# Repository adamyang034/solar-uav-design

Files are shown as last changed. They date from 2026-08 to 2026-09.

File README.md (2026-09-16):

# Solar UAV Design Toolchain

Models for an 81-hour (89 h with margin) solar-powered flight attempt in the
Mojave desert. Twin-boom, OV-10-style configuration, 6 m span / 12 kg limits.

## Status

- **Phase 1 — environment**: `solar_uav/environment.py`. Clear-sky
  plane-of-array irradiance at the mission site (pvlib/Ineichen), sun-angle
  and reflection (IAM) losses, design-day temperatures, NOCT-style cell
  temperature calibrated to 75 °C at solstice noon.
- **Phase 2 — components**: `solar_uav/components/`
  - `solar_array.py` — SunPower C60 electrical model, boost-MPPT string
    limit, wing/H-stab cell layout with bay/joint constraints.
  - `battery.py` — Upgrade Energy GOLD V1 6S2P bank: SOC window (20–100%),
    6 A/pack charge limit with CV taper, OCV + internal resistance.
  - `propeller.py` — APC PER3 archive plus Mejzlik 2-blade electric
    datasheets/performance maps, thrust/power interpolators with uncertainty.
    - `motor.py` — Hacker A40-12L V4 kv410 direct (default). Geared 10L/10S
      stay in the catalog for comparisons only.
  - `airfoils.py` — NeuralFoil polars (S4110, S4310, AG35, NACA 0010),
    AeroSandbox-native objects for the Phase 3/4 optimization.
- **Phase 3 — aircraft coupling**: `solar_uav/aircraft.py`. Twin-boom
  geometry (H-stab span = boom spacing), mass buildup from measured areal
  densities, NeuralFoil drag polar + induced + parasite, stall/min-power
  speeds, static margin (CG at c/4), elevator trim and pitch acceleration.
  AeroSandbox VLM / AeroBuildup / mesh inertia / XFoil are a conservative
  envelope (`solar_uav/asb_physics.py`): friendlier ASB numbers are discarded.
- **Phase 4 — energy closure + optimizer**: maximize the lower morning SOC,
  requiring next morning SOC not to decrease and retaining the 20% floor.
  `scripts/run_six_layout_study.py` now defaults to an AeroSandbox/IPOPT
  smooth surrogate followed by exact catalog-neighborhood verification.
  It relaxes prop diameter/pitch and pack count alongside geometry, then
  recomputes integer cell packing, battery behavior, and all existing gates.
  The previous differential-evolution search is retained with `--method de`;
  older standalone scripts such as `run_phase34.py` still use that path.
  The 89-hour trace is visualization, not an additional acceptance gate.
  See [surrogate search](docs/surrogate-search.md) and
  [morning SOC and yaw](docs/morning-soc-and-yaw.md).
- **Phase 5 — uncertainty**: `solar_uav/monte_carlo.py`. Sobol sample of
  irradiance, cell temperature, array efficiency, mass growth, drag, APC
  thrust/power factors, avionics, and pack energy. Reports P(closure),
  P10/P50/P90 margin, tornado, and Spearman drivers.
- **Phase 6 — validation**: `solar_uav/validation.py`. Bench/flight
  protocols (panel, battery, thrust stand, glide polar). Drop measured
  CSVs in `data/validation/measured/`; the fitter recommends updates to
  the FLAGGED factors. A synthetic self-test checks the fitter without
  lab data.
- **CAD visualizer**: `solar_uav/cad.py` builds the twin-boom solid
  (AeroSandbox mesh + solar cells + props), writes STL / OpenSCAD, a
  three-view drawing, and `outputs/aircraft_viewer.html`. The four-configuration
  compare view (π-tail, split empennage, conventional, conventional rectangular) is
  `outputs/compare/aircraft_viewer.html` and is what GitHub Pages serves.
  The rectangular option fixes wing taper to 1 and geometric twist to 0;
  the original conventional option still optimizes both. Each has two battery options.
  The engineering workspace includes a read-only overview, baseline comparisons,
  CAD and mass breakdowns, energy histories, requirement headroom, and source
  provenance. See [AircraftView](docs/aircraftview.md) for rebuilding and verification.

```bash
.venv/bin/python scripts/validate_all.py    # Phases 1–2
.venv/bin/python scripts/eval_stability.py  # aileron / fin / loiter
.venv/bin/python scripts/run_asb_audit.py   # AeroSandbox vs handbook
.venv/bin/python scripts/run_phase34.py     # Phases 3–4 + optimizer
.venv/bin/python scripts/run_phase56.py     # Phases 5–6 + CAD
.venv/bin/python scripts/visualize.py       # refresh CAD and open the viewer
.venv/bin/python scripts/run_six_layout_study.py --output outputs/new_surrogate_run
```

## Assumptions

All locked constants and **flagged assumptions** live in
`solar_uav/config.py` — grep for `FLAGGED` to review what still needs test
data or a decision (cell bin, OCV curve, pack DCIR, ESC/gearbox
efficiencies, prop-data uncertainty factors, ambient temps, etc.).

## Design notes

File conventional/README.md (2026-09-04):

# Conventional optimizer (fork)

Clone of the single-empennage toolchain so that folder's results stay
untouched.

**Layout:** one fuselage, one tractor motor/prop, one centerline boom,
conventional tail (H-stab in the wing plane, one V-stab further aft).
No H-stab solar. Packs cap at 3. Props need not be sold in both
rotations.

**Construction:** single 1.5 in boom (FLAGGED: one load path vs two 1 in
twin-boom tubes). Fuselage and ESC fixed masses are not halved.

**Energy (same scoring as the π-tail closer):** GVB-8 buck/boost strings
(cold Voc ≤ 50 V, 210 W panel cap), 2 or 3 packs, two-day march with no
98% refill gate. Boom is 1.5 in (kept).

```bash
.venv/bin/python conventional/scripts/run_phase34.py --search
.venv/bin/python conventional/scripts/visualize.py
```

AircraftView (Phase 4 winner): `http://127.0.0.1:8101/`.
`data/` is a symlink to the parent repository (prop maps, polars).

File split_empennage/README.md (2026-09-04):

# Split-empennage optimizer (fork)

Clone of the π-tail toolchain so that folder's results stay untouched.

**Layout:** two identical fuselages, each with its own T-tail. No bridging
H-stab, no H-stab solar. Tails are **not** sized from `V_H`/`V_V`. The
H-stab is inverted from `SM_MIN = 0.08`. Fins are structural T-tail posts
(boom fitting); weathercock, yaw damping, and differential-thrust yaw
are not constraints. No T-tail downwash credit.

**Construction:** tail surfaces and H-stab/V-stab interfaces are 0.75× the
π-tail areal build (user, FLAGGED until weigh-in). Carbon booms start at
the wing trailing edge, not at c/4.

**Energy (same scoring as the π-tail closer):** GVB-8 buck/boost strings
(cold Voc ≤ 50 V, 210 W panel cap), 2 or 3 packs, two-day march with no
98% refill gate. Wing areal is 0.8× the old 0.84 kg/m² model.

```bash
.venv/bin/python split_empennage/scripts/run_phase34.py
.venv/bin/python split_empennage/scripts/visualize.py
```

Viewer: `split_empennage/outputs/aircraft_viewer.html`.
`data/` is a symlink to the parent repository (prop maps, polars).

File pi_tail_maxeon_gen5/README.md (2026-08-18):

# π-tail optimizer — Maxeon Gen 5 (Kn)

Clone of the single-empennage toolchain with Maxeon Gen 5 cells. Root
`solar_uav/` stays C60.

**Layout:** twin-boom π-tail. One H-stab spans the booms. H-stab chord
floor is one cell row (elevator keep-out), not a full Voc-legal string.

**Cells:** Kn bin (5.84 W, 22.6%), 161.7 mm, 167 mm pitch, 11.6 g.
GVB-8 8 A input is **FLAGGED** and not a search hard-fail (Kn Imp 9.88 A).

```bash
.venv/bin/python pi_tail_maxeon_gen5/scripts/run_phase34.py
.venv/bin/python pi_tail_maxeon_gen5/scripts/run_phase34.py --search
.venv/bin/python pi_tail_maxeon_gen5/scripts/visualize.py
```

Viewer: `http://127.0.0.1:8100/`.
`data/` is a symlink to the parent repository (prop maps, polars).

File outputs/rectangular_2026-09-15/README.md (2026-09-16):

# Conventional Rectangular Wing Study

Separate conventional configuration: constant chord and airfoil across the wing,
taper ratio 1, geometric washout 0 degrees. Whole-wing trim incidence remains
available. Conventional rudder checks, mission assumptions, reserve floor, and
hardware choices are unchanged. The tapered conventional option is preserved.

Both runs use the AeroSandbox/IPOPT surrogate workflow with 72 initial geometry
samples, three refinement rounds, three starts, six workers, and seed 7. Seeds
come from the corresponding conventional result in `../surrogate_final_2026-09-15`;
all seeds are reconstructed as rectangular wings and re-evaluated.

| Battery | Packs | Span (m) | Chord (m) | Mass (kg) | Morning SOC | Reserve above 20% (Wh) |
|---|---:|---:|---:|---:|---:|---:|
| GOLD V1 | 3 | 6.000 | 0.378750 | 10.563 | 29.567% | 138.625 |
| 6S 36 Ah | 2 | 6.000 | 0.390604 | 11.190 | 28.068% | 118.481 |

Both use catalog propeller MJ-20x11EWL and pass the current modeled constraints.
The next-morning SOC condition passes within the existing numerical tolerance.
These are best-found designs, not guaranteed global optima or flight-qualified
aircraft. Structural sizing and existing model uncertainties remain separate.

The two runs performed 663 exact single-prop evaluations in approximately 137
seconds combined. All 486 retained candidate rows have the required fixed geometry.
AircraftView independently recomputed both winners and matched the search SOC
within 0.000001 percentage points. The viewer combines these two cases with the
six preserved cases from `../surrogate_final_2026-09-15`.

Per-case manifests record fixed and active geometry, battery configuration,
source seeds, bounds, and timing. Sample and surrogate diagnostics accompany
each candidate CSV. `browser_qa` contains visual and interaction checks.

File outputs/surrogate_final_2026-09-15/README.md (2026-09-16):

# Final Surrogate-Search Validation

The six-case runner now defaults to a differentiable response-surface search with
AeroSandbox/IPOPT, followed by original-model checks of nearby real catalog props,
allowed integer pack counts, and exact cell packing. See ../../docs/surrogate-search.md.

## Results

All six winners passed fresh energy, hard-constraint, and applicable yaw checks.
The fresh viewer simulations reproduce the final search values to floating-point
precision. These remain preliminary model passes, not flight qualification.

| Layout | Battery | Packs | Mass (kg) | Morning SOC (%) | Reserve above 20% (Wh) |
|---|---|---:|---:|---:|---:|
| Single empennage / pi-tail | GOLD V1 | 3 | 10.843 | 26.1584 | 89.24 |
| Split empennage | GOLD V1 | 3 | 10.135 | 31.4475 | 165.87 |
| Conventional | GOLD V1 | 3 | 9.840 | 37.6531 | 255.79 |
| Single empennage / pi-tail | 6S 36 Ah | 2 | 11.045 | 25.7141 | 83.92 |
| Split empennage | 6S 36 Ah | 2 | 10.363 | 30.7844 | 158.38 |
| Conventional | 6S 36 Ah | 2 | 10.207 | 36.4487 | 241.56 |

The split/36 Ah result improved from 30.5898% to 30.7844% morning SOC (about
2.86 Wh extra reserve). The other five retained their reverified previous winners.

## Runtime

| Case | New run (s) | Prior DE run (s) | Exact single-prop evaluations |
|---|---:|---:|---:|
| Single / GOLD | 76.2 | 436.0 | 259 |
| Split / GOLD | 78.7 | 1157.2 | 273 |
| Conventional / GOLD | 75.4 | 387.2 | 295 |
| Single / 36 Ah | 57.5 | 2235.9 | 239 |
| Split / 36 Ah | 66.8 | 404.9 | 269 |
| Conventional / 36 Ah | 62.1 | 322.4 | 323 |
| Total | 416.9 | 4943.6 | 1658 |

Total recorded case runtime: about 7.0 minutes versus 82.4 minutes previously.
These timings include each case's catalog loading and search, but not viewer
generation, development trials, or browser verification. The new runs warm-start
from the previous optimized geometries. This is not a controlled cold-start
benchmark or a guarantee of the same runtime reduction on future designs.

## Method and Limitations

- 72 additional stratified geometry samples per case, three refinement rounds,
  up to three starts per manufacturer per round, seed 7, six workers.
- Neighbor windows: +/-2.5 inches diameter and +/-2.0 inches pitch, plus nearest
  available SKUs for sparse windows. All catalog variants in the window are tested.
- Twenty selected proposals came from successful IPOPT solves. Sixteen
  manufacturer/round attempts instead used the documented exact-neighborhood
  fallback around known samples. Those fallbacks are not claimed as solver optima.
- The fit is approximate, particularly across cell-packing changes; holdout
  errors, solver failures, trust radii, and predicted/exact scores are recorded in
  each `.surrogate.json`. Fitted scores are never aircraft acceptance results.
- The 16x12E power-map warnings on twin-fuselage designs remain. Structural and
  hardware qualification remain separate; no requirements were loosened.
- Earlier development trials are retained in the other `surrogate_*` directories
  and labeled superseded. This directory contains the final implementation run.

## Verification

The regression suite passes for all three layouts, including analytic-gradient
checks, a known AeroSandbox optimum, catalog-only neighbors, allowed pack counts,
preloaded-map behavior, numerical-bound handling, and morning-SOC/yaw checks.
AircraftView browser checks cover all six selectors, nonblank moving 3D models,
89-hour trace endpoints and chart data, desktop/mobile screenshots, and script errors.

Exact CSVs remain compatible with the existing viewer builder. The published
viewer and fresh verification summary are in ../compare/aircraft_viewer.html and
../compare/study_results.json.

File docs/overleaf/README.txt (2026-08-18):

Solar UAV optimizer guide — Overleaf pack
========================================

Upload this whole folder to Overleaf (New Project → Upload Project),
or zip main.tex + figures/ + this README and drop the zip on Overleaf.

Compiler: pdfLaTeX
Main file: main.tex
Two passes (table of contents + list of figures).

figures/ were generated from the live nearest-miss on 17 August 2026:

  three_view.png        CAD mesh, four views
  geometry_top.png      planform
  geometry_side.png     independent H/V tails
  mass_breakdown.png    kg lumps
  airfoil_polars.png    NeuralFoil @ Re 150k
  drag_budget.png       night drag shares
  power_vs_speed.png    polar + DV(V) and the 1.3 Vs floor
  solstice_day.png      El Mirage irradiance / sun / cell T
  battery_ocv.png       6S OCV vs SOC
  mission_power.png     array vs night/day bus
  mission_soc.png       24 h march
  tradespace.png        812 DE candidates

To refresh the PNGs from the Python model:

  .venv/bin/python scripts/export_overleaf_figures.py

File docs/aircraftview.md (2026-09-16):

# AircraftView Engineering Workspace

AircraftView is a read-only review of eight calculated layout/battery cases.
The engineering interface is authored in `scripts/engineering_view.html` and
`scripts/aircraft_view/`; `scripts/build_compare_viewer.py` regenerates the served
files in `outputs/compare/`. No optimization or physics model was changed for
this redesign.

## Review Views

- Overview: morning SOC, reserve above the floor, mass/headroom, night bus power,
  lift/drag, battery energy, actual CAD mesh, critical requirements and case ranking.
- Compare: select any combination of the eight cases, choose a baseline and view
  absolute values, unit-aware differences or both. Positive does not always mean
  better: only unambiguous performance directions receive green/red coloring.
- Geometry: native generated mesh, camera presets and layers, planform dimensions,
  modeled mass ledger, illustrative inertia and airfoil sections.
- Mass breakdown: total mass, takeoff limit/headroom and battery fraction; whole-
  aircraft allocation pie followed by component pies and expandable constituent
  tables. Select a portion to jump to its detail; units toggle between kg and g.
- Energy: scored morning-cycle quantities separated from the 89-hour display,
  power histories, battery/controller inputs and night drag budget.
- Requirements: model limits, calculated values, dimensional headroom, tolerances,
  and pass/fail/not-evaluated status. These are not structural FoS margins.
- Model & sources: source CSV/manifest, file and current model-source hashes,
  search/recomputed SOC agreement, assumptions, input values and search bounds.

The default interface is monochrome. Color identifies plotted series, CAD
components, statuses and meaningful comparison differences. Light/dark theme is
stored locally. Configuration and view are encoded in the URL, so a link returns
to the same selection. CAD is read-only: legacy browser-only layout and mass edits
are intentionally not consumed as results.

## Data Contract

`engineering_snapshot.py` derives review metadata from the selected `Design`,
active configuration and actual mission acceptance thresholds. Each displayed
case is reconstructed and re-simulated by the existing builder. No stale formatted
overview strings are used as numerical sources. The snapshot retains full-precision
values; presentation rounding does not determine pass/fail.

`mass_allocation.py` derives the mass page from `Design.mass_breakdown()` and the
configured fixed budgets, not from CAD placement lumps. It uses consistent
airframe, battery, solar/power, propulsion and avionics/controls categories across
all layouts. Solar cells and interconnects are separate from airframe structure;
fixed items are assigned once by function. Parent/child sums and the final mass
are checked when building. Detailed spar/rib/fastener masses are not invented.
Identical packs, motors, propellers and controllers use equal per-item allocations.

The snapshot source hash covers the candidate CSV. The model-source hash covers
the current layout package's Python files, not the complete external data/runtime
environment or a historical search-code revision. Run metadata comes from its
saved manifest. The displayed reconstruction check is not empirical validation.

Exports include selected-case JSON (full data/provenance), selected-comparison CSV
(absolute values and provenance), and the actual airframe STL. CSV always exports
unrounded absolute values, regardless of the current delta-display setting.

Model-feasible does not mean flight-qualified. Structural strength, buckling and
aeroelasticity remain explicitly unassessed. Aerodynamic stability's assumed
quarter-chord CG is distinguished from illustrative CAD component positions.
The extended trace starts at full charge and is not the morning-cycle acceptance
test. The old standalone layout viewers are not modified by this redesign.

## Build and Verify

```sh
OPENBLAS_NUM_THREADS=1 VECLIB_MAXIMUM_THREADS=1 OMP_NUM_THREADS=1 .venv/bin/python scripts/build_compare_viewer.py --results-dir outputs/surrogate_final_2026-09-15 --rectangular-results-dir outputs/rectangular_2026-09-15
.venv/bin/python -m unittest discover -s tests -p 'test_*.py'
node tests/check_engineering_view.cjs http://127.0.0.1:8765/aircraft_viewer.html outputs/engineering_review_2026-09-15/qa
node tests/check_mass_view.cjs 'http://127.0.0.1:8765/aircraft_viewer.html?cfg=conventional__6s_36ah&view=mass' outputs/engineering_review_2026-09-15/mass_qa
```

Browser verification requires Playwright, Chrome and Sharp. It checks every case
and view, source agreement, real CAD pixels, camera movement, chart coordinates,
exports, comparisons, filters, dark theme and 390/768/1024/1920-pixel layouts.
Generated UI assets and the icon license live in `outputs/compare/lib/review/`,
which the existing GitHub Pages workflow publishes with the bundled libraries.

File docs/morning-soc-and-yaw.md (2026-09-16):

# Morning SOC and Yaw Acceptance

Updated 2026-09-15.

## Energy Objective

- Start with a full ground-charged battery at the last afternoon solar surplus.
- March through the night without resetting the battery.
- Record current morning SOC immediately before solar surplus begins charging.
- March one complete day to the same charging transition the next morning.
- Require next morning SOC >= current morning SOC. Equality is not required.
- Only 1e-9 SOC of floating-point tolerance is allowed; there is no daily Wh-loss allowance.
- Among feasible aircraft maximize the lower of those two morning SOC values, in percent, not Wh.
- Retain the 20% minimum SOC, unmet-energy, and existing climb checks.

The result fields are `morning_soc`, `next_morning_soc`,
`morning_soc_change`, `morning_charge_hour`, and `objective_soc`.
`soc_start` and `soc_end` now refer to the two morning boundaries.
`margin_wh` still reports energy above the minimum SOC over the scored cycle;
it is not the optimization objective. Failed designs cannot outrank passing
ones just by retaining more energy in a large battery.

Morning is detected from the first daily transition from nonpositive to
positive solar-minus-load power. This uses the existing clear-sky design-day
profile. A profile without a charging transition cannot satisfy this test.
Multiple weather-driven charging episodes would need an explicit event policy
before using a weather-based mission model.

## Visualization and Deferred Work

The main, conventional and separate-tail viewers use an independent 89-hour
SOC/energy trace, beginning at 08:00 with a full battery. The repeated design
day is intentional for visualization; it is not an 89-hour weather forecast
or the acceptance horizon. Bank angle is assumed negligible, so no turning
drag penalty has been added.

The assumed buck/boost MPPT and its current mass are retained. Electrical
capability refinements and structural sizing remain deferred by user decision.

## Yaw and Rudder

Two-motor layouts use differential thrust. Their authority check is independent
of the switch controlling passive yaw-stability requirements. The conventional
single-fuselage layout calls the rudder check directly, without a differential-
thrust capability calculation.

The conventional geometry already included a full-span rudder at 30% of fin
chord and 20 degrees maximum deflection. This installed geometry is retained.
New sizing output reports required versus installed chord fraction, chord,
area, available/required moment, and sideslip/yaw-rate margins.

The existing aerodynamic approximation is retained:

    tau = sqrt(rudder chord / fin chord)
    N_available = q S b Cn_delta_r delta_r_max
    N_required = max(N_sideslip, |N_r| r_required)
    required chord fraction = (N_required / N_per_unit_tau)^2

Sideslip correction and yaw rate are separate cases, as in the original model.
The effectiveness model's 5%-60% chord domain is enforced. A too-small installed
rudder fails; the code does not silently enlarge it or shrink the current rudder.
Servo torque, hinge loads, response time and simultaneous maneuver demands are
not newly validated by this calculation.

For a local smoke check of the saved conventional GOLD V1 winner geometry:

| Quantity | Calculated value |
|---|---:|
| Rudder span | 0.4765 m |
| Installed chord | 0.09531 m |
| Required chord | 0.03277 m |
| Installed area | 0.04542 m2 |
| Required area | 0.01562 m2 |
| Sideslip moment margin | +70.5% |
| Steady yaw-rate moment margin | +736.1% |

This check restored the GOLD V1 pack constants and 20-inch prop diameter; XFoil
was disabled for the local smoke check. It was not a new optimization or a
flight-control certification.

## Verification

Run `.venv/bin/python -m unittest discover -s tests -v` from the repository root.
For each layout, run the same interpreter from that layout directory with
`-m unittest discover -s ../tests -v`. Tests cover rising/equal/falling morning
SOC, precharge boundary timing, absence of charging, feasibility-first ranking,
SOC versus Wh ranking, 89-hour display separation, legacy CSV handling, yaw
routing, and rudder sizing limits.

Existing CSVs and exported HTML are historical artifacts and have not been
overwritten. They do not contain the new morning fields. Rerun the search and
viewer exporter to produce new winning designs and updated exported graphs;
old CSVs retain their historical ranking rather than receiving invented morning
SOC values.

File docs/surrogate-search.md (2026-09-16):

# Differentiable Surrogate Search

## What Was Slow

The previous production search used differential evolution for ten geometry
coordinates, separately for two and three battery packs. Every surviving geometry
ran an inner comparison of the 51 filtered catalog propellers. It was not a full
Cartesian grid of all variables: cell counts came from geometry, cruise speed used
a nested numerical search, and the motor was fixed. Propeller performance maps
were normally cached, but their performance was still evaluated repeatedly.

## New Six-Case Default

1. Load catalog maps once in the parent and distribute them to workers. This also
   avoids concurrent writes to the vendor's local catalog index.
2. Reevaluate up to twelve previous leading designs with the current physics.
   Old mission scores are not imported as training labels or accepted results.
3. Sample every catalog prop at the incumbent geometry and allowed pack counts,
   once, plus 72 stratified geometry samples, half global and half local.
4. Fit smooth, ridge-regularized Gaussian radial-basis models with affine trends
   for morning SOC, minimum SOC, daily SOC change, climb, unmet energy, and the
   original model's feasibility outcome. Analytic leave-one-out error selects
   regularization strength; grouped held-out cases remain separate from tuning.
   Fits use normalized coordinates and are
   separate for APC and Mejzlik. The feasibility fit is a heuristic, not a
   calibrated probability.
5. Use `aerosandbox.Opti` / IPOPT to optimize geometry, continuous pack count,
   diameter, and pitch. Multistart anchors cover both pack counts. Prop proposals
   stay inside the manufacturer's catalog diameter/pitch convex hull and a local
   radius; geometry stays within a bounded local trust region.
   Tolerance-sized solver drift is projected back onto the original bounds
   before exact evaluation; the aircraft limits themselves are unchanged.
6. Check actual SKUs within +/-2.5 inches diameter and +/-2.0 inches pitch of each
   proposed optimum. Keep all catalog variants in that window, filling sparse
   windows with the five closest available SKUs. Check neighboring allowed pack
   counts, including both counts at an endpoint in the current two/three-pack set.
   Also check +/-5 mm chord and boom-spacing changes to cross packing boundaries.
7. Recompute exact geometry, integer cells/strings, real prop maps, prop mass,
   electrical model, yaw, all existing hard gates, and the mission. Add these
   evaluations to training and repeat, three rounds by default. Shrink the trust
   region after poor predictions, no feasible neighbors, or no improvement.

Only exact original-model rows enter the candidate CSV or become winners. A
fractional propeller, fractional battery pack, or fitted SOC result never becomes
a reported aircraft. The previous winner is retained only after current-model
reevaluation. Layouts, battery options, and manufacturer families remain genuine
categories; motor and ESC choices remain fixed as before. Cell counts are smoothed
implicitly in the response versus geometry, not treated as installable fractions.

The current catalog filter is unchanged (including its pitch/diameter window).
If a proposed size is absent, no nonexistent combination is created. For example,
a 22.5 x 23.25 inch prop is outside the current filtered data support.

## Accuracy and Limits

This is surrogate-assisted local optimization, not an end-to-end differentiable
rewrite of the flight model or proof of a global optimum. The numerical solver
can exploit response-surface errors; geometry-dependent packing and hard limits
are particularly difficult to fit. Reports include grouped holdout morning-SOC
RMSE, solver status, predicted versus verified neighborhood SOC, and trust radii.
Large errors reduce the proposal radius; exact verification remains mandatory.

The smooth proposal problem permits up to 0.002 SOC recovery error and 0.1 Wh
unmet energy to avoid rejecting useful neighborhoods purely because of fitting
noise. These are **not** changed aircraft requirements. Final acceptance still
uses the original 1e-9 morning-SOC numerical tolerance, reserve, climb, unmet-energy,
and control checks. Invalid or overly optimistic proposals are discarded.

Runtime comparisons against the archived differential-evolution run are warm-start
workflow comparisons, not equal-budget, cold-start global-search benchmarks.
The one-time catalog sampling/preload cost still exists. Solver failures are
recorded and fall back to exact neighborhoods of known samples, not an unverified
"optimum." Existing structural and hardware/model-uncertainty caveats still apply.

## Commands and Outputs

```sh
.venv/bin/python scripts/run_six_layout_study.py --output outputs/new_surrogate_run --workers 6
.venv/bin/python scripts/run_six_layout_study.py --output outputs/new_de_run --method de --workers 6
```

Optional controls: `--samples`, `--rounds`, `--starts`, `--diameter-radius`,
`--pitch-radius`, `--combo`, and `--seed-dir`. The default seed directory is the
archived six-case morning-SOC run; if a case is missing, its legacy candidate
file supplies geometry seeds instead. A completed run is resumed only with matching search settings and seed path;
use a new output directory after physics/model changes.

Each case writes exact candidates (`.csv`), configuration/timing (`.json`),
surrogate fit/solve diagnostics (`.surrogate.json`), and all sampled inputs plus
their exact outcomes (`.samples.json`). The existing comparison-viewer builder
accepts the new results directory without a different result schema.

Solver API: [AeroSandbox Opti documentation](https://aerosandbox.readthedocs.io/en/master/autoapi/aerosandbox/optimization/opti/index.html).

## Rectangular Conventional Variant

The runner now supports four configurations and two batteries (eight cases);
its historical filename is retained. `conventional_rectangular` reuses the
conventional single-fuselage physics, motor, and rudder checks. It fixes wing
taper ratio to 1 and tip washout to 0. The now-irrelevant taper/washout start
positions are fixed to 1 and 0 respectively. The four fixed coordinates are
removed from the search vector, leaving six geometry variables. Whole-wing
incidence for trim is unchanged; there is no spanwise variation in incidence.

`study_variants.py` applies these restrictions before optimizer import in both
the parent and spawned workers. The viewer validates the reconstructed geometry.
The original conventional configuration remains unrestricted. If no rectangular
seed file exists, conventional geometry seeds are projected into the reduced
search space and re-evaluated; their old mission scores are never reused.

```sh
.venv/bin/python scripts/run_six_layout_study.py --output outputs/rectangular_2026-09-15 --seed-dir outputs/surrogate_final_2026-09-15 --combo conventional_rectangular__gold_v1
.venv/bin/python scripts/run_six_layout_study.py --output outputs/rectangular_2026-09-15 --seed-dir outputs/surrogate_final_2026-09-15 --combo conventional_rectangular__6s_36ah
.venv/bin/python scripts/build_compare_viewer.py --results-dir outputs/surrogate_final_2026-09-15 --rectangular-results-dir outputs/rectangular_2026-09-15
```

The viewer can combine the new cases with the six archived results without
overwriting or rerunning those studies; source CSV paths are retained in its data.

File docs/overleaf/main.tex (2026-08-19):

\documentclass[11pt,letterpaper]{article}

\usepackage[margin=1in]{geometry}
\usepackage{amsmath,amssymb,amsfonts}
\usepackage{booktabs}
\usepackage{longtable}
\usepackage{array}
\usepackage{tabularx}
\usepackage{enumitem}
\usepackage{hyperref}
\usepackage{xcolor}
\usepackage{setspace}
\usepackage{fancyhdr}
\usepackage{caption}
\usepackage{graphicx}
\usepackage{float}
\usepackage{subcaption}
\graphicspath{{figures/}}

\hypersetup{
  colorlinks=true,
  linkcolor=blue!50!black,
  urlcolor=blue!50!black,
  citecolor=blue!50!black
}

\setstretch{1.12}
\setlist[itemize]{leftmargin=1.4em,itemsep=0.25em}
\setlist[enumerate]{leftmargin=1.6em,itemsep=0.25em}
\setlength{\parskip}{0.35em}
\setlength{\parindent}{0pt}

\pagestyle{fancy}
\fancyhf{}
\lhead{Solar UAV optimizer}
\rhead{How the model actually works}
\cfoot{\thepage}

\newcommand{\flag}{\textcolor{red!60!black}{\textbf{FLAGGED}}}
\newcommand{\code}[1]{\texttt{#1}}

\newenvironment{intuition}{\begin{quote}\small}{\end{quote}}
\newenvironment{examplebox}{\begin{quote}\small}{\end{quote}}
\newenvironment{warningbox}{\begin{quote}\small}{\end{quote}}

\title{\textbf{How the Solar UAV Optimizer Works}\\[0.4em]
\large Assumptions, constraints, physics, and what the numbers are trying to tell us}
\author{Design toolchain notes for new members\\
\texttt{solar-uav-design} repository}
\date{17 August 2026}

\begin{document}
\maketitle
\tableofcontents
\listoffigures
\newpage

% =====================================================================
\section{Start here: the one-page mental model}
% =====================================================================

This repository is not a CAD package and it is not a gradient-based ``optimal control'' solver.
It is a \textbf{physics model plus a discrete search}. For each candidate airplane it answers one question:

\begin{quote}
\textit{If this airframe flies a clear-sky solstice day at our site, with our packs and our motors, does the repeating day stay above 20\% overnight and not get poorer?}
\end{quote}

If yes, the design \emph{closes}. If not, the model reports how far it missed, in watt-hours. Nothing on the locked grid currently closes.

The night, not the day, is the problem. On a June solstice the array makes on the order of 200\,W at noon. Cruise only needs about 75\,W of bus power. The airplane still fails because for about \textbf{14 hours} the array cannot cover cruise, and two packs only store 773\,Wh of usable energy.

\begin{intuition}
\textbf{Intuition.} Think of the battery as a water tank, the motors as a tap, and the solar array as a daytime hose. Closing is not ``does the hose fill the tank to 100\%?'' Closing is ``can the tank last until the hose starts working again, and is Tuesday's tank at least as full as Monday's?'' Extra noon solar that you cannot store does not help the night. Launching full is a one-night gift; the scored day is the next one.
\end{intuition}

Three numbers dominate almost every trade:

\begin{enumerate}
  \item \textbf{Night bus power} --- electrical watts the two motors plus avionics draw in level night loiter.
  \item \textbf{Battery-true night length} --- hours when array power is less than that night load (not sunset-to-sunrise).
  \item \textbf{Usable pack energy} --- $2 \times 483\,\mathrm{Wh} \times 80\% = 773\,\mathrm{Wh}$.
\end{enumerate}

Aero, mass, props, and motors all matter only insofar as they move those three numbers.

Source of truth for locked constants: \code{solar\_uav/config.py}. Every value marked \flag{} is an assumption awaiting a measurement or a team decision. The physics rule is: when uncertain, take the \textbf{pessimistic} side. A design must not close because the model was kind.

% =====================================================================
\section{The airplane and the mission}
% =====================================================================

\subsection{What we are designing}

Twin-boom, OV-10-style solar UAV:

\begin{itemize}
  \item One three-piece wing (S4310): rectangular inboard bay between the booms, two outboard panels that may taper. Leading edge unswept.
  \item Independent tails: NACA~0010 H-stab spanning the booms \emph{in the wing plane}; two NACA~0010 V-stabs further aft (fin LE behind H-stab TE). Not a $\pi$-tail.
  \item One tractor propeller and one motor on each boom.
  \item SunPower C60 cells on the wing top and on the H-stab (ahead of the elevator).
  \item Two Upgrade Energy GOLD V1 6S packs in parallel, Genasun GVB-8-Li-25.0V MPPTs (buck and boost; one per string).
\end{itemize}

\begin{figure}[htbp]
  \centering
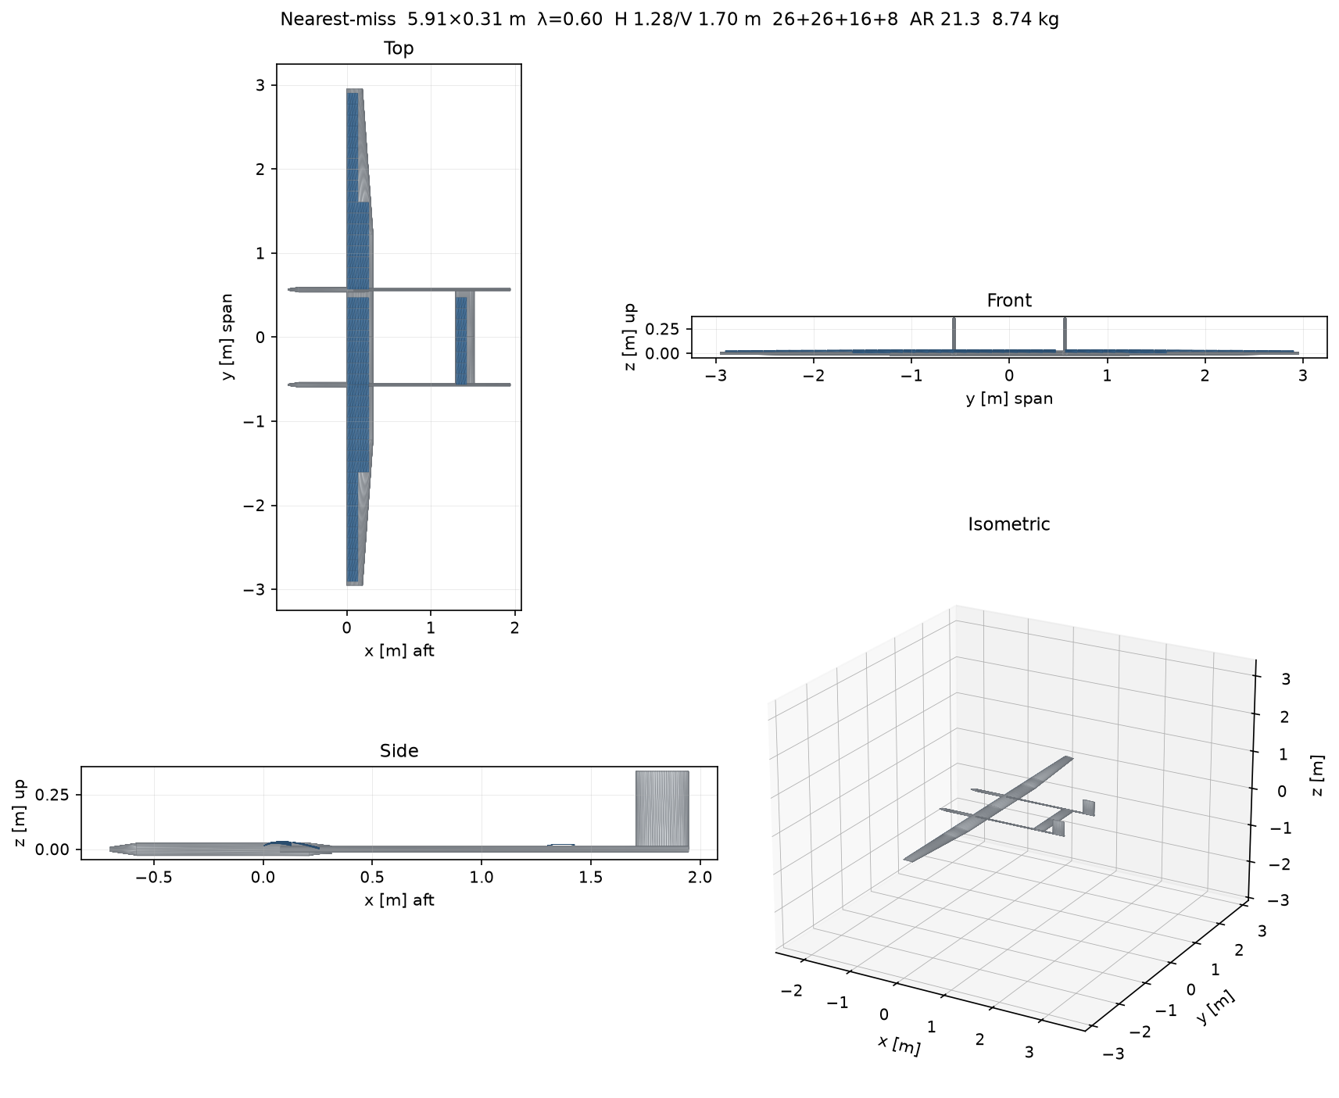
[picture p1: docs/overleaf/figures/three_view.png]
  
  \caption{Current nearest-miss three-view from the live CAD mesh: $5.91\times 0.314\,\mathrm{m}$, $\lambda=0.60$, H-arm $1.28\,\mathrm{m}$, V-arm $1.70\,\mathrm{m}$, 76 cells ($26+26+16+8$), $8.74\,\mathrm{kg}$. H-stab in the wing plane; V-stabs further aft. Blue patches are C60 cells.}
  \label{fig:threeview}
\end{figure}

No payload. The mission is an 81-hour endurance record, designed to 89 hours (10\% margin). The optimizer launches the design day from a full pack (ground charge), then scores the \textbf{next} 24 hours: dawn must stay at or above 20\%, and that repeating day must not get poorer (start $\le$ end). A first night that only survives because you took off full is not closed.

\subsection{Locked mission requirements}

\begin{center}
\begin{tabular}{@{}ll@{}}
\toprule
Quantity & Value \\
\midrule
Site latitude & $34.646849^\circ\mathrm{N}$ (El Mirage Race Course) \\
Site longitude & $-117.605977^\circ$ (El Mirage Race Course) \\
Site elevation & $2837\,\mathrm{ft} = 864.7\,\mathrm{m}$ MSL (USGS lake bed) \\
Cruise AGL & $400\,\mathrm{ft}$ (density at field + AGL; no ground-effect credit) \\
Timezone & America/Los\_Angeles \\
Design day & 21 June 2027 (solstice, longest day) \\
Mission window & 1 May -- 31 July 2027 \\
MTOW & $\le 12\,\mathrm{kg}$ \\
Span & $\le 6\,\mathrm{m}$ \\
Packs & exactly two (no third pack) \\
Avionics & $5\,\mathrm{W}$ continuous, day and night (measured) \\
Climb & $\ge 1.5\,\mathrm{m/s}$ \flag{} \\
Min airspeed & $\max(1.2\,V_\mathrm{stall},\; 15\,\mathrm{kt})$ \\
SOC window & 20\%--100\% (80\% of nameplate is usable) \\
\bottomrule
\end{tabular}
\end{center}

Temperatures are a \textbf{hot design-day}: ambient $24^\circ\mathrm{C}$ dawn to $40^\circ\mathrm{C}$ afternoon \flag{}. A real El Mirage June dawn is often cooler and denser. Keeping $24^\circ\mathrm{C}$ dawn is conservative for night aero. Afternoon $40^\circ\mathrm{C}$ is not a desert extreme --- revisit if cells run hotter than the 75\,$^\circ\mathrm{C}$ noon calibration.

% =====================================================================
\section{The conservative-physics rule}
% =====================================================================

If a number is not measured and not in a datasheet range, the model implements the side that makes closure \emph{harder}.

\begin{itemize}
  \item \textbf{Prop maps.} If the (speed, RPM) point is on the manufacturer table, use that $T$ and $P$, density-scaled. Similarity $C_T(J)$ is a check, or a fallback only while the blade is still below windmill $J$. Never invent a slower RPM at fixed speed once a tabulated block already covers that speed.
  \item \textbf{ESC / motor.} Do not treat 95\% ESC efficiency as valid below $\sim$50\% duty. Low-RPM cruise is not a free no-load-current win.
  \item \textbf{Aero.} Do not take unmodeled credits (T-tail height reducing downwash, flight cooling, swirl recovery) unless they \emph{hurt} the metric you care about. Handbook downwash $2C_L/(\pi\,\mathrm{AR})$ is already coarse --- do not ``improve'' it in the direction that lightens tail download.
  \item \textbf{Mass / solar / battery.} Heavier structure, less array, stricter charge limits --- not the reverse.
\end{itemize}

\begin{warningbox}
\textbf{Why this exists.} An earlier interpolator $n^2$-scaled a $22\times12$E propeller down to $\sim$1190\,RPM at night cruise, inventing $J \approx 1.14$ past the map's zero-thrust $J \approx 0.67$. Night bus looked like $\sim$62\,W and the airplane ``closed.'' The honest operating point on the table is $\sim$2070\,RPM and $\sim$133--138\,W. Prefer an honest fail over an optimistic close.
\end{warningbox}

% =====================================================================
\section{What kind of optimizer this is}
% =====================================================================

File: \code{solar\_uav/optimize.py}.

It is a \textbf{mixed continuous / discrete search}. Aero geometry (span, chord, H-stab arm, V-stab arm, boom spacing, taper, washout, elevator fraction) is continuous and is driven by differential evolution (\code{search\_continuous()}). Integer and catalog quantities stay discrete: cell count from packing, pack count (locked at 2), motor (A40-12L direct), ESC (fixed mass), and the inner-loop propeller pick.

A legacy exhaustive grid (\code{search()}) remains for neighborhood dumps. Do not use it as the production path --- it is the slow nested loop that used to take tens of minutes.

The inner loop (\code{\_best\_prop}) is not part of the outer product. For each airframe it:

\begin{enumerate}
  \item Tries every shortlisted propeller.
  \item Keeps only those that can make night thrust on 6S.
  \item Ranks them by night bus power (lowest first).
  \item Accepts the first that also meets the $1.5\,\mathrm{m/s}$ climb rule.
\end{enumerate}

So ``the optimizer evaluated 51 props'' does \emph{not} mean $51\times$ the airframe grid. Each airplane picks one fan.

Ranking of results: closed designs first, then highest \code{margin\_wh}. If none closed, the top row is the nearest miss.

Default motor is the A40-12L kv410 direct-drive. Geared A40-10L / 10S stay in the catalog for compare scripts only and are not searched.

% =====================================================================
\section{Optimization objective}
% =====================================================================

\textbf{Maximize 24-hour energy margin} (watt-hours above the 20\% SOC floor on the repeating day), subject to periodicity, climb, MTOW, span, solar layout, and trim/pitch.

After the two-day march (day 1 from SOC $=1$, day 2 from wherever day 1 ended),

\begin{align}
  E_\mathrm{reserve}
    &= (\mathrm{SOC}_\mathrm{min} - 0.20)\,E_\mathrm{pack,total}, \\
  E_\mathrm{cycle}
    &= (\mathrm{SOC}_\mathrm{end} - \mathrm{SOC}_\mathrm{start})\,E_\mathrm{pack,total}, \\
  \mathrm{margin}
    &= E_\mathrm{reserve}.
\end{align}

$\mathrm{SOC}_\mathrm{min}$, $\mathrm{SOC}_\mathrm{start}$, and $\mathrm{SOC}_\mathrm{end}$ are all on \textbf{day 2}. $E_\mathrm{cycle}$ is a diagnostic: it must be $\ge -0.5\,\mathrm{Wh}$ to close, but it is not stacked into the score. If the pack could not supply the requested power at any step, margin is also capped at $-\,E_\mathrm{unmet}$.

\begin{intuition}
\textbf{Intuition.} $\mathrm{SOC}_\mathrm{min}$ is ``did we scrape the floor at dawn on the repeating day?'' $\mathrm{SOC}_\mathrm{end} \ge \mathrm{SOC}_\mathrm{start}$ is ``is Tuesday at least as rich as Monday?'' A design that holds 20\% on the first night from a full launch and then ratchets is not a winner. We do not require the pack to hit 98\%.
\end{intuition}

A design is \textbf{closed} only if all of these hold:

\begin{itemize}
  \item $\mathrm{SOC}_\mathrm{min} \ge 0.20$ (day 2)
  \item unmet energy $< 0.5\,\mathrm{Wh}$ (day 2)
  \item climb $\ge 1.5\,\mathrm{m/s}$
  \item $E_\mathrm{cycle} \ge -0.5\,\mathrm{Wh}$ (day 2 does not get poorer)
\end{itemize}

Margin on the current nearest-miss, scored on the repeating day, is worse than the old first-night figure: $\mathrm{SOC}_\mathrm{min} = 0.007$, a $-28\,\mathrm{Wh}$ cycle, and $80\,\mathrm{Wh}$ unmet. The 20\% floor is still what fails. Extra noon solar mostly spills; you need energy \emph{during the night}. The old 98\% refill gate is gone; this row also ratchets.

% =====================================================================
\section{Constraints}
% =====================================================================

\subsection{Hard constraints (candidate is discarded before the mission march)}

Implemented in \code{\_hard\_constraints} and the packing checks:

\begin{center}
\begin{tabular}{@{}lp{0.62\textwidth}@{}}
\toprule
Name & Rule \\
\midrule
Span & $b \le 6\,\mathrm{m}$ \\
Mass & $m \le 12\,\mathrm{kg}$ (re-checked after the prop is chosen) \\
Solar layout & cells fit the bays; each series string stays within the GVB-8 Voc/power cap \\
Stall & $1.2\,V_\mathrm{stall} \le 25\,\mathrm{m/s}$ (sanity cap) \\
Stability & static margin $\ge 8\%\,\mathrm{MAC}$, elevator trim, pitch acceleration $\ge 0.30\,\mathrm{rad/s^2}$, roll rate $\ge 35^\circ/\mathrm{s}$, differential-thrust yaw vs $5^\circ$ sideslip and yaw rate $\ge 5^\circ/\mathrm{s}$ (no rudder). $C_{n_\beta}$ / $|C_{n_r}|$ floors off; derivatives still computed. \\
Boom & carbon tube length $> 0.4\,\mathrm{m}$ \\
V-stab / H-stab & V-stab leading edge at or behind H-stab trailing edge (also enforced by flooring $\ell_v$) \\
Propulsion & some shortlisted prop can make night thrust on 6S \emph{and} climb \\
\bottomrule
\end{tabular}
\end{center}

\subsection{Energy constraints (scored, not discarded)}

Candidates that fail the SOC floor or the day-2 cycle are still written to the CSV so we can see nearest misses. Climb failure also appears in the reason string.

\subsection{Electrical / packing constraints baked into geometry}

\begin{itemize}
  \item One series string per bay on the locked search (inboard, left outboard, right outboard, H-stab). Strings do not cross joints.
  \item The GVB-8 bucks and boosts, so string Voc may sit above the 6S bus. Remaining caps: cold-cell Voc $\le 50\,\mathrm{V}$ (recommended STC Voc; 60\,V is the absolute input) and STC string power $\le 210\,\mathrm{W}$. That is \textbf{61 cells}/string on bin I (the 210\,W rating binds before 50\,V).
  \item Genasun input $\le 8\,\mathrm{A}$; C60 $I_\mathrm{mp} \approx 5.9\,\mathrm{A}$, so one series string per MPPT is fine.
  \item Layout pitch $130\,\mathrm{mm}$ (cell is $125\,\mathrm{mm}$ plus gap). A $300\,\mathrm{mm}$ chord still fits two rows.
  \item After packing, every claimed cell is placed as a $125\,\mathrm{mm}$ square and rejected if it overlaps another cell or hangs off the planform (taper, aileron keep-out, elevator keep-out).
  \item H-stab cells only on the fixed portion; elevator chord is keep-out (split elevons).
  \item Tapered wing: no cells on the aileron chord. Rectangular wing: cells may cover ailerons.
\end{itemize}

% =====================================================================
\section{Decision variables and search grids}
% =====================================================================

Aero variables are continuous. Integer / catalog items stay discrete. Every continuous quantity has a \texttt{(low, high, start)} triple in \code{config.CONTINUOUS}. User-locked starts (chord $310\,\mathrm{mm}$, tail arm $0.90\,\mathrm{m}$, airspeed $12\,\mathrm{m/s}$) are not overwritten.

\begin{center}
\begin{tabular}{@{}lll@{}}
\toprule
Variable & Bounds / start & Notes \\
\midrule
\multicolumn{3}{l}{\emph{In the DE vector}} \\
Span $b$ & $4.50$--$6.00\,\mathrm{m}$, start $6.00$ & hard cap $6\,\mathrm{m}$ \\
Root chord $c_r$ & $0.300$--$0.52\,\mathrm{m}$, start $310\,\mathrm{mm}$ & two C60 rows; high = four pitches \\
H-stab arm $\ell_t$ & $0.80$--$2.00\,\mathrm{m}$, start $0.90$ & wing AC to H-stab AC \\
V-stab arm $\ell_v$ & $0.80$--$3.00\,\mathrm{m}$, start $1.20$ & floored so V-stab LE $\ge$ H-stab TE \\
Elevator fraction & $0.22$--$0.40$, start $0.34$ & split elevons; keep-out for H-stab cells \\
Taper $\lambda = c_\mathrm{tip}/c_r$ & $0.40$--$1.0$, start $0.60$ & $1.0$ is rectangular; $0.40$ still packs a tip cell \\
Taper start & $0$--$1$ of outboard, start $0.50$ & $0$ = taper from the boom \\
Boom spacing & $1.04$--$2.21\,\mathrm{m}$, start $1.30$ & $8$--$17$ cell pitches; H-stab span = boom spacing \\
Washout tip & $0^\circ$--$5^\circ$, start $0^\circ$ & $5^\circ$ is a lot at this AR \\
Washout start & $0$--$1$ of outboard, start $0$ & unused at $0^\circ$ washout \\
\midrule
\multicolumn{3}{l}{\emph{Continuous, nested (not DE)}} \\
Loiter airspeed & $8$--$18\,\mathrm{m/s}$, start $12$, $0.01\,\mathrm{m/s}$ step & still floored by $1.3\,V_s$ / $15\,\mathrm{kt}$ \\
\midrule
\multicolumn{3}{l}{\emph{Continuous, held at start}} \\
H-stab AR & $3.5$--$6.0$, start $4.5$ & not in the DE vector \\
V-stab AR & $1.5$--$3.5$, start $1.5$ & per fin; held at start \\
Aileron chord frac & $0.20$--$0.30$, start $0.25$ & locked for S\&C sizing \\
\midrule
\multicolumn{3}{l}{\emph{Discrete / catalog}} \\
Packs & $\{2\}$ & locked, integer \\
Motor & A40-12L kv410 direct & not searched \\
ESC & fixed $0.060\,\mathrm{kg}$ lump & not searched \\
$N_\mathrm{cells}$ & from packing & integer, one MPPT-legal string per bay \\
Prop & inner loop, see \S\ref{sec:props} & discrete catalog \\
\bottomrule
\end{tabular}
\end{center}

The production search is \code{optimize.search\_continuous()} (differential evolution, start at the DE table above). A neighborhood grid dump is optional via the legacy \code{search()} path.

% =====================================================================
\section{How one candidate is scored}
% =====================================================================

Walk this loop in your head for every row of the CSV.

\begin{enumerate}
  \item Build geometry: planform, boom spacing, H-stab in the wing plane sized to $V_H = 0.50$ (chord also floored by one cell row), V-stabs to $V_V = 0.030$ at their own arm $\ell_v$ (no 1.30\,m area floor), carbon tube from wing $c/4$ to V-stab trailing edge, fuselage pods from wing TE to the prop disk.
  \item Pack cells: one MPPT-legal series string per bay. Reject if cells overlap or hang off the planform.
  \item Sum mass. Drop if $>12\,\mathrm{kg}$.
  \item Check stall, static margin, elevator, pitch, roll rate, weathercock, yaw damping.
  \item For each propeller: night drag at min-power speed $\to$ RPM on the map $\to$ bus watts. Rank by night watts. Keep the cheapest that still climbs at 25.2\,V.
  \item March 24 hours: solar from pvlib, load = night bus or day bus, $P_\mathrm{net} = P_\mathrm{solar} - P_\mathrm{load}$, battery with 6\,A/pack charge cap.
  \item Record $\mathrm{SOC}_\mathrm{min}$, $\mathrm{SOC}_\mathrm{end}$, margin, flags (especially prop table vs.\ similarity).
\end{enumerate}

The rest of this document is the physics inside those steps.

% =====================================================================
\section{Atmosphere and site}
% =====================================================================

Files: \code{solar\_uav/aircraft.py} (density), \code{solar\_uav/environment.py} (sun and temperature).

Site pressure is ISA-style at field elevation plus $400\,\mathrm{ft}$ AGL ($h \approx 987\,\mathrm{m}$ MSL):

\begin{equation}
  p = 101325
  \left(1 - 2.25577\times 10^{-5}\, h\right)^{5.25588}
  \quad [\mathrm{Pa}].
\end{equation}

Density is the ideal-gas law at that pressure:

\begin{equation}
  \rho = \frac{p}{R T}, \qquad R = 287.05\,\mathrm{J/(kg\,K)}.
\end{equation}

Two densities are frozen for the mission (AeroSandbox ISA at field $+$ 400\,ft AGL, with the design-day temperature offset):

\begin{itemize}
  \item Night: $T = 26^\circ\mathrm{C}$ ($T_\mathrm{amb,min}+2$) $\Rightarrow$ $\rho_N = 1.048\,\mathrm{kg/m^3}$.
  \item Day: $T = 36^\circ\mathrm{C}$ ($T_\mathrm{amb,max}-4$) $\Rightarrow$ $\rho_D = 1.014\,\mathrm{kg/m^3}$.
\end{itemize}

Air viscosity is Sutherland's law at the night temperature, $\mu = 1.84\times 10^{-5}\,\mathrm{Pa\,s}$. Reynolds number of a length $\ell$ is

\begin{equation}
  \mathrm{Re}_\ell = \frac{\rho V \ell}{\mu}.
\end{equation}

\begin{intuition}
\textbf{Intuition.} Hot air is thinner, and El Mirage at $\sim$987\,m MSL is already thinner than sea level. A thinner night means the wing needs a higher $C_L$ (or more speed) to hold the same weight, so induced drag rises. Using a hot dawn is deliberately unkind to night watts. Ground effect is not credited: density is at field $+$ 400\,ft AGL, not a cushion of extra lift near the lake bed.
\end{intuition}

% =====================================================================
\section{Geometry}
% =====================================================================

\subsection{Wing planform}

The wing is three pieces. Inboard, between the booms, the chord is $c_r$. Outboard of each boom the chord stays $c_r$ until a taper-start station, then linearly tapers to $c_\mathrm{tip} = \lambda c_r$. Leading edge unswept, so taper is trailing-edge cut.

Let $y_b$ be half the boom spacing and $L_\mathrm{out} = b/2 - y_b$ the outboard panel length. With taper-start fraction $f$ (0 = start at the boom),

\begin{align}
  L_\mathrm{rect} &= f\, L_\mathrm{out}, \\
  L_\mathrm{tap}  &= (1-f)\, L_\mathrm{out}, \\
  S &= 2 y_b c_r + 2 L_\mathrm{rect} c_r + L_\mathrm{tap}(c_r + c_\mathrm{tip}).
\end{align}

Mean aerodynamic chord for an unswept piecewise-linear planform:

\begin{equation}
  \bar{c} = \frac{2}{S}\int_{-b/2}^{b/2} c(y)^2\,\mathrm{d}y.
\end{equation}

Aspect ratio is the usual $ \mathrm{AR} = b^2 / S $.

Boom spacing and area depend on each other (H-stab span = boom spacing, and $V_H$ uses $S$ and $\bar{c}$), so the code iterates that loop 16 times.

\subsection{Horizontal tail}

Target tail volume

\begin{equation}
  V_H = \frac{S_H \ell_t}{S \bar{c}} = 0.50 \quad \text{\flag{}}.
\end{equation}

When boom spacing is forced (e.g.\ $1.30\,\mathrm{m}$), H-stab span equals that spacing and chord is

\begin{equation}
  c_H = \max\left(\frac{V_H S \bar{c}}{\ell_t\, b_\mathrm{boom}},\;
  c_{H,\min}\right),
\end{equation}

where $c_{H,\min}$ is the chord that still fits one $130\,\mathrm{mm}$ cell row after the elevator keep-out. That is why a short tail arm does not shrink the H-stab to nothing: solar packing floors the chord.

\subsection{Vertical tails}

The V-stab aerodynamic centre sits on its own arm $\ell_v$, independent of the H-stab arm $\ell_t$. Total area (both fins)

\begin{equation}
  V_V = \frac{S_V \ell_v}{S b} = 0.030 \quad \text{(user; both fins together)}.
\end{equation}

There is \textbf{no} fin-area floor at a 1.30\,m arm: stretching $\ell_v$ shrinks $S_V$ at fixed $V_V$. Each fin has area $S_V/2$ and $\mathrm{AR}_V = 1.5$ (held at the start of \code{CONTINUOUS}). No rudder; yaw control is differential thrust. No $\pi$-tail endplate credit on $C_{n_\beta}$.

The V-stab leading edge is required to sit at or behind the H-stab trailing edge:

\begin{equation}
  \ell_v \ge \ell_t + 0.75\, c_H + 0.25\, c_V(\ell_v).
\end{equation}

$c_V$ shrinks as $\ell_v$ grows, so the code iterates to the fixed point and floors any requested $\ell_v$ that would overlap the H-stab in $x$.

\subsection{Boom length}

The carbon tube runs from the wing quarter-chord (at the boom) to the V-stab trailing edge. The fuselage pod covers prop disk $\to$ wing trailing edge and is \emph{not} part of $L_\mathrm{boom}$.

\begin{equation}
  L_\mathrm{boom} = x_{\mathrm{V,TE}} - \tfrac14 c_r,
\end{equation}

where $x_{\mathrm{V,TE}} = \tfrac14 \bar{c} + \ell_v + \tfrac34 c_V$. The H-stab camber is in the \textbf{wing plane} ($z_H = 0$); the fins stand up from the boom further aft. Fuselage length and CAD-scaled wetted area (one pod):

\begin{align}
  L_\mathrm{fuse} &= 0.70\,\mathrm{m} + c_r, \\
  S_{\mathrm{wet,fuse}} &= 173128.421\,\mathrm{mm}^2 \times \frac{L_\mathrm{fuse}}{980\,\mathrm{mm}}.
\end{align}

The $980\,\mathrm{mm} / 173128.421\,\mathrm{mm}^2$ point is from CAD. Linear scale assumes constant section (motor/spinner girth does not grow with chord).

\begin{figure}[htbp]
  \centering
  \begin{subfigure}[t]{0.48\textwidth}
    \centering
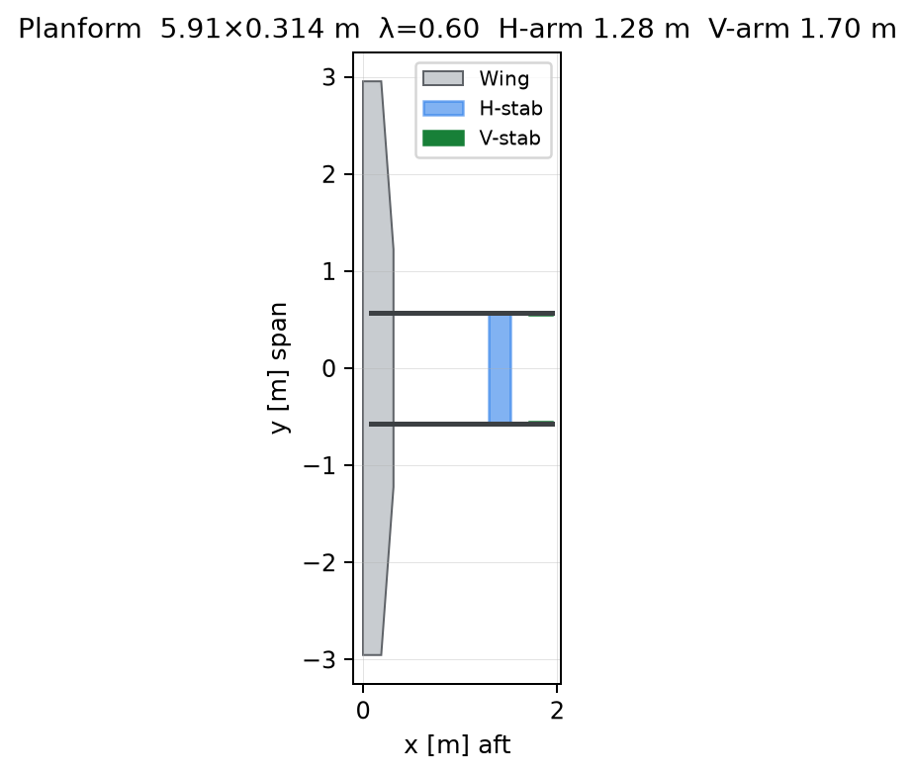
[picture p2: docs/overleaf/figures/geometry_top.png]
    
    \caption{Planform (equal scale).}
  \end{subfigure}\hfill
  \begin{subfigure}[t]{0.48\textwidth}
    \centering
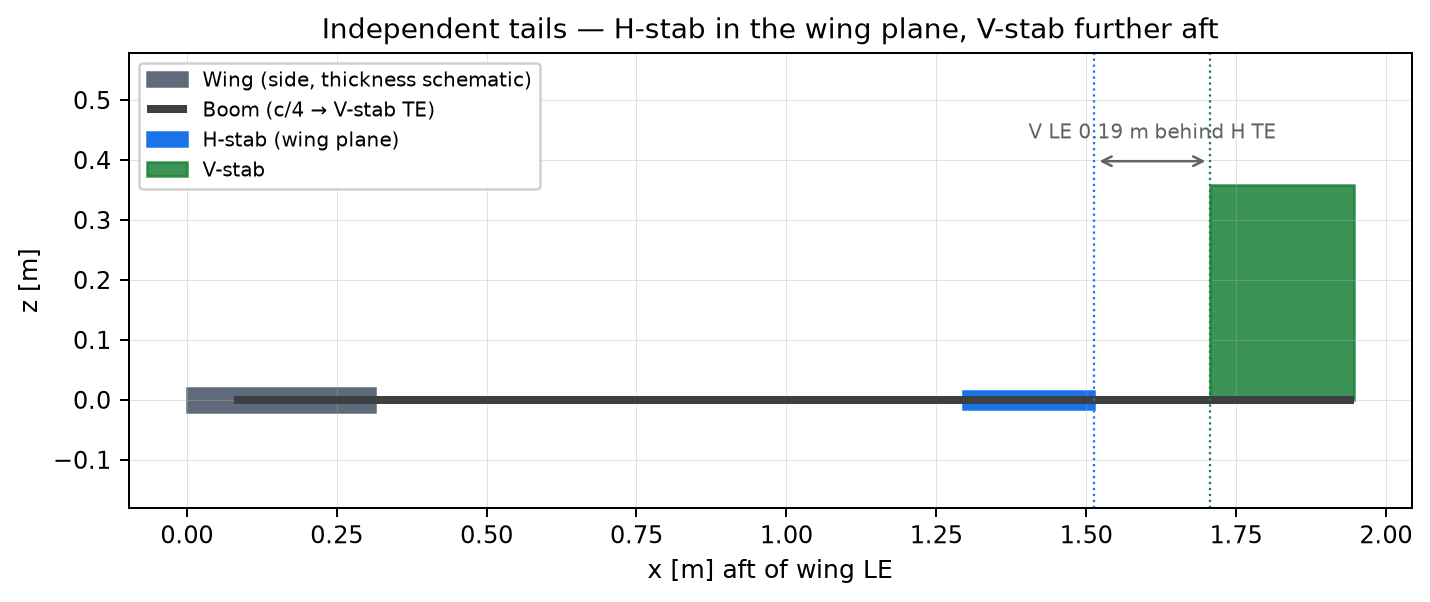
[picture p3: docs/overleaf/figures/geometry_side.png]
    
    \caption{Side schematic.}
  \end{subfigure}
  \caption{Independent tails on the current airplane. Boom runs wing $c/4$ to V-stab trailing edge. V-stab leading edge is $0.19\,\mathrm{m}$ behind the H-stab trailing edge. No $\pi$-tail; $z_H=0$.}
  \label{fig:geometry}
\end{figure}

% =====================================================================
\section{Mass}
% =====================================================================

Wetted-area factor $k_w = 2.05$ (both sides plus a little thickness). Wing structure uses $0.84\times 0.8 = 0.672\,\mathrm{kg/m^2}$ of wetted area (user, 17 August 2026: 0.8$\times$ the previous main-wing model only), \emph{including} encapsulation, \emph{excluding} cells. Tails stay at $0.44\,\mathrm{kg/m^2}$ wetted.

\begin{align}
  m_\mathrm{wing}  &= 2.05\, S \times 0.672, \\
  m_{H}            &= 2.05\, S_H \times 0.44, \\
  m_{V}            &= 2.05\, S_V \times 0.44, \\
  m_\mathrm{booms} &= 2 \times L_\mathrm{boom} \times 0.174\,\mathrm{kg/m}, \\
  m_\mathrm{cells} &= N_\mathrm{cells} (0.0065 + 0.0015)\,\mathrm{kg}, \\
  m_\mathrm{MPPT}  &= N_\mathrm{strings} \times 0.108\,\mathrm{kg}, \\
  m_\mathrm{batt}  &= 2 \times 1.278\,\mathrm{kg}.
\end{align}

Boom linear density $0.174\,\mathrm{kg/m}$ is the 1.0\,in OD carbon tube (was $0.290\,\mathrm{kg/m}$ at $\varnothing 38.1\,\mathrm{mm}$). Parasite drag uses the 25.4\,mm OD.

Fixed masses (prototype table): avionics 0.30, power boards 0.10, servos 0.08, ESCs 0.06, wiring 0.096, fuselage pods 0.20, superstructures 0.20, boom/V-stab interfaces 0.10, boom/H-stab fittings 0.06 (same lump as the old $\pi$-tip joint). Total fixed $= 1.196\,\mathrm{kg}$.

Motors and props are catalog masses (two of each).

\begin{examplebox}
\textbf{Worked example --- current nearest-miss} ($b=5.91$, $c_r=0.314$, $\lambda=0.60$, $\ell_t=1.28$, $\ell_v=1.70$, 76 cells).

\begin{center}
\begin{tabular}{@{}lr@{}}
\toprule
Item & Mass [kg] \\
\midrule
Wing structure & 2.25 \\
H-stab & 0.22 \\
V-stabs & 0.15 \\
Booms ($2\times 1.87\,\mathrm{m}\times 0.174$) & 0.65 \\
Cells + interconnect & 0.61 \\
Four MPPTs & 0.43 \\
Two packs & 2.56 \\
Two A40-12L & 0.55 \\
Two APC $16\times12$E & 0.12 \\
Fixed & 1.20 \\
\midrule
\textbf{Total} & \textbf{8.75} \\
\bottomrule
\end{tabular}
\end{center}

The 0.8$\times$ wing areal cut $\sim$0.6\,kg off the previous 0.84\,kg/m$^2$ wing. The 1\,in tube is both lighter per metre and thinner in parasite drag than the 1.5\,in / 0.290\,kg/m boom. The V-stabs are smaller than a co-located $\pi$-tail at $\ell_t$ because $\ell_v$ is longer at fixed $V_V$. Batteries are still the heaviest single lump.
\end{examplebox}

\begin{figure}[htbp]
  \centering
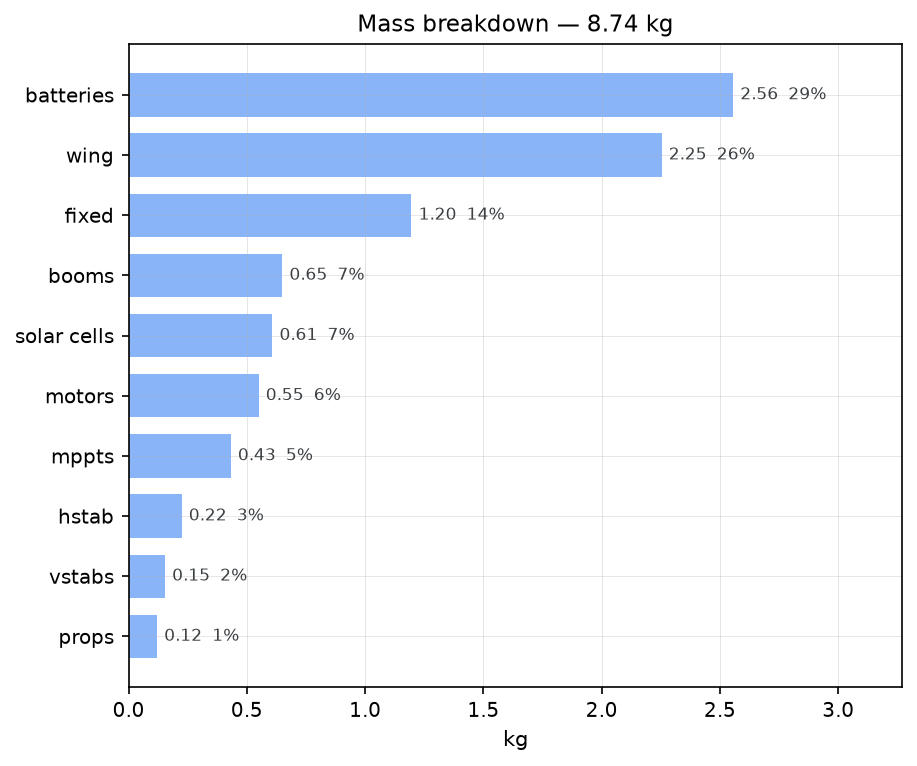
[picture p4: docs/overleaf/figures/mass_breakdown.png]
  
  \caption{Mass lumps on the current nearest-miss. Batteries $2.56\,\mathrm{kg}$ and wing structure $2.25\,\mathrm{kg}$ dominate. Booms are $0.65\,\mathrm{kg}$ at $0.174\,\mathrm{kg/m}$.}
  \label{fig:mass}
\end{figure}

\begin{intuition}
\textbf{Intuition.} You do not ``buy'' span for free. A 6\,m wing at 0.672\,kg/m$^2$ wetted is already $\sim$2.3\,kg before cells. Lengthening $\ell_v$ (not just $\ell_t$) adds carbon on \emph{both} booms, because the tube still runs to the V-stab trailing edge. That extra mass flies all night.
\end{intuition}

% =====================================================================
\section{Aerodynamics}
% =====================================================================

File: \code{solar\_uav/aircraft.py}. Airfoil polars: NeuralFoil \code{xlarge} via AeroSandbox, cached in \code{data/polars/}. Wing section is S4310; tails are NACA~0010. Polar grid: $\mathrm{Re} \in \{50,100,150,200,300\}\times 10^3$, $\alpha \in [-6^\circ, 16^\circ]$ at $0.25^\circ$.

NeuralFoil polars are not monotonic in $C_L$ at negative $\alpha$. The code takes the \textbf{increasing-$C_L$ pre-stall branch} (from $C_{L,\min}$ to $C_{L,\max}$), then interpolates $c_d$, $\alpha$, and $c_m$ versus $C_L$ and $\log\mathrm{Re}$.

\begin{figure}[htbp]
  \centering
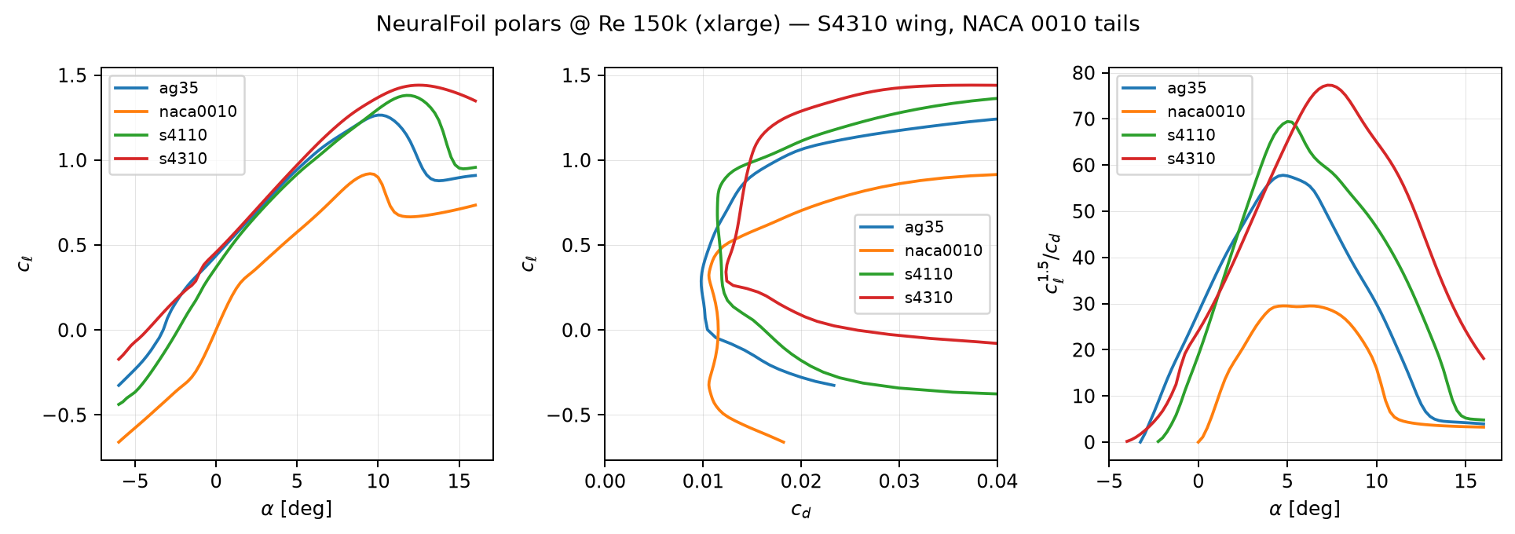
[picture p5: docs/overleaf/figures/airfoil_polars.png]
  
  \caption{Cached NeuralFoil \texttt{xlarge} polars at $\mathrm{Re}=1.5\times 10^5$. Production uses S4310 on the wing and NACA~0010 on both tails.}
  \label{fig:airfoils}
\end{figure}

\subsection{Level-flight lift}

Dynamic pressure and net lift coefficient (weight on the wing reference area):

\begin{equation}
  q = \tfrac12 \rho V^2, \qquad
  C_{L,\mathrm{net}} = \frac{mg}{q S}.
\end{equation}

The H-stab carries a (usually negative) load, so the wing must make a little more than $C_{L,\mathrm{net}}$:

\begin{equation}
  C_{L,w}\, S + C_{L,H}\, S_H = mg
  \quad \Rightarrow \quad
  C_{L,w} = C_{L,\mathrm{net}} - \frac{S_H}{S} C_{L,H}.
\end{equation}

$C_{L,H}$ is not a guess. It comes from the trim iteration below.

\begin{intuition}
\textbf{Intuition.} $C_{L,\mathrm{net}}$ is ``how hard is this wing working, as a whole, to hold the airplane up?'' If the tail is pushing down, the wing has to make \emph{more} lift than the weight, and induced drag is paid on that higher wing $C_L$. That is why a badly trimmed tail is not free.
\end{intuition}

\subsection{Lift-curve slopes (Helmbold)}

Finite-wing lift slope, per radian:

\begin{equation}
  a = \frac{2\pi}{1 + 2/\mathrm{AR}}.
\label{eq:helmbold}
\end{equation}

Used for the wing ($a_w$) and the H-stab ($a_t$ with the H-stab's actual AR). This is the classical correction that a high-AR wing is closer to $2\pi$ and a stubby tail is much less.

Downwash derivative at the tail, handbook:

\begin{equation}
  \frac{\mathrm{d}\varepsilon}{\mathrm{d}\alpha} = \frac{2 a_w}{\pi\,\mathrm{AR}}.
\end{equation}

\subsection{Oswald efficiency (induced-drag factor)}

Rectangular calibration $e_0 = 0.90$ \flag{}. Taper scales that using AeroSandbox's Nita--Scholz estimate:

\begin{equation}
  e = \min\left(0.98,\;
      e_0 \frac{e_\mathrm{Nita}(\lambda_\mathrm{eq},\mathrm{AR})}
               {e_\mathrm{Nita}(1,\mathrm{AR})}\right).
\end{equation}

$\lambda_\mathrm{eq}$ is an equivalent taper from the actual area and tip chord, clipped to $[0.2, 1]$. The 0.98 cap is a hard ceiling: we do not claim a better-than-nearly-elliptical wing.

On the current $\lambda = 0.60$, $\mathrm{AR} = 21.3$ airplane, this \textbf{hits the 0.98 cap}.

\begin{intuition}
\textbf{Intuition.} Induced drag is the price of making lift with a finite wing: the tip vortices tilt the lift vector backward. Elliptical spanload pays the minimum price, $C_{D_i} = C_L^2/(\pi\,\mathrm{AR})$. Oswald $e$ is ``how close are we to that ellipse?'' $e=0.90$ is an honest rectangle. $e=0.98$ is ``this taper already did most of the job.'' That is why adding washout on top of $\lambda=0.4$ does not buy much --- there is almost no induced-drag left to save, and the cap forbids claiming more.
\end{intuition}

\subsection{Induced drag of the wing}

\begin{equation}
  C_{D_i,w} = \frac{C_{L,w}^2}{\pi\,\mathrm{AR}\, e}.
\label{eq:cdi}
\end{equation}

If washout is zero, that is the whole induced model. If washout is nonzero, $e$ is replaced by an effective $e$ from lifting-line (see \S\ref{sec:washout}).

\subsection{Wing profile drag}

At the local $(C_{L,w}, \mathrm{Re}_{\bar{c}})$, read $c_d$ from the S4310 NeuralFoil polar:

\begin{equation}
  C_{D_{p,w}} = c_{d,\mathrm{S4310}}\!\left(C_{L,w},\, \mathrm{Re}_{\bar{c}}\right).
\end{equation}

This is a 2D section drag treated as constant across the span when washout is zero. With washout, a strip integral adds the difference vs.\ the untwisted wing (again \S\ref{sec:washout}).

\subsection{Horizontal-stabilizer drag}

Profile from NACA~0010 at the tail's $C_{L,H}$ and $\mathrm{Re}_{c_H}$. Induced with a conservative tail Oswald $e_H = 0.70$:

\begin{equation}
  C_{D_{p,H}} = c_{d,0010}(C_{L,H}, \mathrm{Re}_{c_H}), \qquad
  C_{D_{i,H}} = \frac{C_{L,H}^2}{\pi\,\mathrm{AR}_H \cdot 0.70}.
\end{equation}

These coefficients are referenced to $S_H$, not $S$.

\subsection{Vertical-stabilizer drag}

Both fins at $C_L = 0$ (no sideslip in the cruise model):

\begin{equation}
  C_{D_{p,V}} = c_{d,0010}(0, \mathrm{Re}_{c_H}),
\end{equation}

referenced to $S_V$ (the H-stab chord Reynolds number is used as a stand-in for the fin). No induced term: they are not lifting in this model.

\subsection{Parasite drag of pods and booms}

Turbulent skin friction (Blasius-like power law, floored at $\mathrm{Re}=10^4$):

\begin{equation}
  C_f = \frac{0.074}{\mathrm{Re}^{0.2}}.
\end{equation}

Two fuselage pods. Wetted area is interpolated from CAD ($173128.421\,\mathrm{mm}^2$ at $L=980\,\mathrm{mm}$), Reynolds number on the actual pod length $L_\mathrm{fuse} = 0.70\,\mathrm{m}+c_r$, form factor 1.25:

\begin{equation}
  f_\mathrm{pods} = 2\, C_f(\mathrm{Re}_{L_\mathrm{fuse}}) \cdot 1.25 \cdot S_{\mathrm{wet,fuse}}(L_\mathrm{fuse}).
\end{equation}

Two circular booms, wetted area $\pi D L$ per tube, $D = 1.0\,\mathrm{in} = 25.4\,\mathrm{mm}$, form/interference 1.10 on the booms, then another 1.10 on the sum:

\begin{align}
  f_\mathrm{booms} &= 2\, C_f(\mathrm{Re}_L) \cdot 1.10 \cdot (\pi D L_\mathrm{boom}), \\
  f_\mathrm{parasite} &= 1.10\,(f_\mathrm{pods} + f_\mathrm{booms}).
\end{align}

$f$ is a drag area: $D = q f$. No laminar-run credit, no T-tail wake shielding.

\subsection{Putting drag together}

\begin{equation}
\begin{aligned}
  D = q \Big[&
      S \bigl(C_{D_{p,w}} + C_{D_{i,w}}\bigr)
    + S_H \bigl(C_{D_{p,H}} + C_{D_{i,H}}\bigr) \\
    &+ S_V C_{D_{p,V}}
    + f_\mathrm{parasite}
  \Bigr] \times k_\mathrm{trim}.
\end{aligned}
\label{eq:drag}
\end{equation}

$k_\mathrm{trim} = 1.00$. There is no lumped ``trim drag fudge.'' Trim is modeled by actually loading the tail.

\subsection{Incidence and trim}
\label{sec:trim}

The wing is jigged so the \textbf{booms fly at $\alpha \approx 0$} at night min-airspeed. That is a structural / packaging choice (the carbon tubes want to be at zero), not an aerodynamic optimum.

NeuralFoil gives the 2D geometric angle $\alpha_{2D}$ that produces the cruise $C_L$ on S4310. The wing also has an induced angle $C_L/(\pi\,\mathrm{AR}\,e)$. Boom angle of attack is

\begin{equation}
  \alpha_\mathrm{boom} = \alpha_{2D} + \frac{C_L}{\pi\,\mathrm{AR}\,e} - i_w.
\end{equation}

Setting $\alpha_\mathrm{boom}=0$ at the design point:

\begin{equation}
  i_w = \alpha_{2D}(C_L) + \frac{C_L}{\pi\,\mathrm{AR}\,e}.
\label{eq:iw}
\end{equation}

On the current airplane, $i_w \approx 3.70^\circ$.

The H-stab is jigged so the \textbf{elevator is $\approx 0$} at that same point. Handbook downwash at the tail:

\begin{equation}
  \varepsilon = \frac{2 C_{L,w}}{\pi\,\mathrm{AR}}
  \qquad \text{(radians; no T-tail height credit)}.
\label{eq:eps}
\end{equation}

Section $c_m$ about $c/4$ from NeuralFoil, tail volume $V_H$, tail lift slope $a_t$:

\begin{equation}
  i_t = \varepsilon + \frac{c_m}{V_H a_t}
  \qquad \text{(angles in consistent units)}.
\label{eq:it}
\end{equation}

On the current airplane, $i_t \approx 0.07^\circ$.

Inside \code{drag\_n}, three iterations:

\begin{enumerate}
  \item From current $C_{L,w}$, get $\alpha_{2D}$ and $\alpha_i = C_{L,w}/(\pi\,\mathrm{AR}\,e)$.
  \item Boom $\alpha_f = \alpha_{2D} + \alpha_i - i_w$.
  \item $C_{L,H} = a_t\,(\alpha_f + i_t - \varepsilon)$.
  \item $C_{L,w} \leftarrow C_{L,\mathrm{net}} - (S_H/S) C_{L,H}$.
\end{enumerate}

\begin{intuition}
\textbf{Intuition for \eqref{eq:eps}.} A lifting wing throws air down. The tail flies in that descending wake, so it sees a more negative angle than the boom. $\varepsilon \approx 2C_L/(\pi\,\mathrm{AR})$ is the standard horseshoe-vortex estimate: more lift or less AR $\Rightarrow$ stronger downwash. A T-tail sits higher, in weaker downwash. The H-stab is in the \textbf{wing plane}, so there is no height credit to take. If VLM at that $z_H=0$ is \emph{stronger} than handbook, production uses VLM (currently $k_\varepsilon \approx 1.21$). We never keep a $k_\varepsilon<1$ ``T-tail'' gift.
\end{intuition}

AeroSandbox is used as a \textbf{conservative envelope}, not as the scoring polar (\code{solar\_uav/asb\_physics.py}):

\begin{itemize}
  \item Atmosphere is the AeroSandbox ISA at field $+$ 400\,ft AGL, with the design-day temperature offset.
  \item Wing-only VLM downwash at the real H-stab height ($z_H=0$): if it is \emph{weaker} than \eqref{eq:eps}, keep the handbook (no T-tail credit). If it is stronger, use VLM. Induced $e$ is $\min(e_\mathrm{handbook}, e_\mathrm{VLM})$.
  \item AeroBuildup $C_{l_p}$, $C_{n_\beta}$, $C_{n_r}$: keep the number that makes roll rate, weathercock, or yaw damping \emph{harder}.
  \item Pitch inertia is $\max($lumped, CAD-located \code{MassProperties} $I_{yy})$. Area-painted thin-shell inertia is printed as a FLAG and not used.
  \item XFoil vs NeuralFoil at cruise $C_L$: inflate section $c_d$ if XFoil is draggier; never deflate. If the XFoil binary is missing, FLAG and keep NeuralFoil.
\end{itemize}

Run \code{scripts/run\_asb\_audit.py} to print the envelope on the reference airplane.

\subsection{Static margin}

CG is locked at the wing quarter-chord \flag{}. Neutral-point shift is then entirely the tail:

\begin{equation}
  \mathrm{SM}
    = V_H \frac{a_t}{a_w}
      \left(1 - \frac{\mathrm{d}\varepsilon}{\mathrm{d}\alpha}\right).
\end{equation}

Target was 12\% MAC; minimum accepted is 8\%. The current airplane sits at \textbf{43\% MAC} --- very stable. $V_H$ comes out $0.69$ rather than the $0.50$ volume target because the H-stab chord is floored by one $130\,\mathrm{mm}$ cell row after the elevator keep-out. That extra tail is packing, not an SM request.

Elevator effectiveness is the empirical stand-in $\tau = \sqrt{c_e/c}$ \flag{}. Elevator must trim a $\Delta C_L = 1$ at $\le 15^\circ$. Pitch acceleration about the CG must reach $0.30\,\mathrm{rad/s^2}$ ($\sim 20^\circ$ in 1.5\,s from rest) at min airspeed.

\subsection{Stall and the speeds we actually fly}

2D $C_{L,\max}$ is the peak of the NeuralFoil pre-stall branch. 3D knockdown:

\begin{equation}
  C_{L,\max,3\mathrm{D}} = 0.90\, C_{L,\max,2\mathrm{D}}.
\end{equation}

For S4310, $C_{L,\max,2\mathrm{D}} \approx 1.44$, so $C_{L,\max,3\mathrm{D}} \approx 1.30$. Stall speed:

\begin{equation}
  V_s = \sqrt{\frac{2mg}{\rho S C_{L,\max,3\mathrm{D}}}}.
\end{equation}

Operational floor (flown loiter speed):

\begin{equation}
  V_{\min} = \max\bigl(1.3\, V_s,\; 7.7\,\mathrm{m/s}\bigr).
\end{equation}

$1.2\,V_s$ remains a never-below stall margin. The 89-hour flight is a banked loiter, so the energy march pays $1.3\,V_s$. The $7.7\,\mathrm{m/s}$ is 15\,kt of required crosswind capability. On the current airplane $1.3 V_s = 11.42\,\mathrm{m/s}$ and \textbf{binds}: unconstrained aero min-power is $\sim$9.2\,m/s ($DV \approx 29\,\mathrm{W}$ vs.\ $36\,\mathrm{W}$ at the floor). That extra 2.2\,m/s is about $+10\,\mathrm{W}$ of night bus.

Cruise is \textbf{not} $V_{\min}$ blindly. It is the speed $\ge V_{\min}$ that minimises shaft power $P_\mathrm{aero} = D V$. The 1-D search is bounded to $8$--$18\,\mathrm{m/s}$, starts at $12\,\mathrm{m/s}$, and refines to $0.01\,\mathrm{m/s}$ (Brent), still floored by the loiter margin. On the current airplane the floor \textbf{is} the min-power point: unconstrained aero min-power is $\sim$9.2\,m/s, but $1.3 V_s = 11.42\,\mathrm{m/s}$ binds.

\begin{intuition}
\textbf{Why min power, not max $L/D$?} Endurance on a battery cares about \emph{watts}, not distance. Max $L/D$ minimises drag (energy per metre). Min $D V$ minimises energy per second. For a solar loiterer the clock is the enemy, so we fly min power. The extra $1.3$ factor (vs.\ $1.2$) is so a $20^\circ$ bank does not eat the stall margin --- $\sqrt{1/\cos 20^\circ}\approx 1.03$, so $1.3$ already covers turn-stall.
\end{intuition}

Climb is the ideal excess-power expression at day min-power speed, using max thrust available on 25.2\,V:

\begin{equation}
  \dot{h} = V \frac{T - D}{mg}.
\end{equation}

No acceleration, no prop-in-climb polar change, no takeoff ground roll. On the 12L + APC $16\times12$E this is $\sim 15\,\mathrm{m/s}$ versus a $1.5\,\mathrm{m/s}$ requirement. Climb is not the constraint. It only vetoes fans that are efficient at cruise but cannot pull.

\subsection{Ailerons, elevons, and fins}
\label{sec:control}

The performance polar does not fly the airplane. Roll, weathercock, and yaw damping are hard constraints so a later sim cannot inherit a 5$^\circ$/s placeholder.

\textbf{Ailerons} are 25\% local chord. On a taper they start where the second cell row drops (or further inboard if 35$^\circ$/s is not met) and carry no cells on the moving surface. On a rectangle, cells may cover the aileron. \textbf{Elevons} are the existing elevator, split left/right, used differentially for extra roll. There is \textbf{no rudder}; yaw is differential thrust.

Steady roll helix (full $20^\circ$ aileron + $20^\circ$ elevon):

\begin{equation}
  \frac{p b}{2V} = -\frac{C_{l_{\delta a}}\delta_a + C_{l_{\delta e}}\delta_e}{C_{l_p}},
  \qquad
  C_{l_{\delta a}} = \frac{2 a_w \tau}{S b}\int_{y_1}^{y_2} c(y)\, y\,\mathrm{d}y.
\end{equation}

$C_{l_p}$ is a high-AR handbook estimate inflated 15\% so the rate is harder to achieve. Acceptance: $p \ge 35^\circ/\mathrm{s}$ at loiter speed ($\sim 20^\circ$ bank in about a second). A 10\,cm tip strip on this wing makes $\sim 5^\circ/\mathrm{s}$ --- that was the sim.

Weathercock and yaw damping (two NACA~0010 fins, Helmbold $a_v$, $\eta=0.90$, no endplate credit):

\begin{equation}
  C_{n_\beta} = \eta a_v V_V, \qquad
  C_{n_r} = -2\eta a_v \frac{S_V}{S}\left(\frac{\ell_v}{b}\right)^2.
\end{equation}

Floors: $C_{n_\beta}\ge 0.10$, $|C_{n_r}|\ge 0.030$ are \textbf{off} (differential thrust is the yaw effector). Derivatives are still computed. Hinge/side-gap drag of ailerons and elevons is added to the polar.

Differential-thrust yaw (one motor $T_{\max}$, the other idle) must overpower weathercock at $5^\circ$ $\beta$. The \textbf{corrective rate} is the still-air heading rate with loiter-preserving $\Delta T$ (one motor up, the other down, sum held at drag) versus $C_{n_r}$:

\begin{equation}
  r = \frac{N_{\mathrm{DT,loiter}}}{q S b\, |C_{n_r}|\, b/(2V)},
  \qquad
  N_{\mathrm{DT,loiter}} = 2\min(T_{\mathrm{cruise}},\, T_{\max}-T_{\mathrm{cruise}})\, y_{\mathrm{boom}}.
\end{equation}

Acceptance: $r \ge 5^\circ/\mathrm{s}$ (unwind $5^\circ$ in about a second). $C_{n_r}$ for this rate is the \emph{more negative} of handbook vs AeroBuildup. $I_{zz}$ sizes the initial $\dot r$ and the 1-DOF time to yaw $5^\circ$; motor spool-up is not modelled, so those two are optimistic. Max-effort (idle one motor) rate is reported and is not the gate.

\textbf{No dihedral} is modelled. Spiral-mode static stability is not claimed; the autopilot is assumed to hold a slow spiral with the sized ailerons.

\subsection{Washout}
\label{sec:washout}

Geometric washout is tip leading-edge down, starting at a station on the outboard panel. \textbf{Zero washout does not change the lumped polar at all} --- the lifting-line code is not even called. That is deliberate, so the published baseline cannot move when someone toggles a unused twist flag.

When twist is nonzero, a Fourier lifting-line (Prandtl / Anderson, 11 odd modes on the half-span, file \code{solar\_uav/lifting\_line.py}) solves

\begin{equation}
  \Gamma(\theta) = 2 b V \sum_{n=1,3,\ldots} A_n \sin(n\theta),
  \qquad y = (b/2)\cos\theta.
\end{equation}

Section lift $c_\ell = 2\Gamma /(V c)$. Wing $C_L = \pi\,\mathrm{AR}\, A_1$. Trefftz-plane Oswald:

\begin{equation}
  e_\mathrm{LL} = \frac{A_1^2}{\sum n A_n^2}.
\end{equation}

The model does \emph{not} replace handbook $e$ with $e_\mathrm{LL}$ outright (that would let an inviscid method invent a better wing than the calibration). It only reports the \emph{ratio} of twisted to untwisted lifting-line $e$, times the handbook value, still capped at 0.98:

\begin{equation}
  e_\mathrm{eff} = \min\left(0.98,\;
    e_\mathrm{handbook} \frac{e_\mathrm{LL,twisted}}{e_\mathrm{LL,untwisted}}\right).
\end{equation}

Strip profile drag is integrated at the collocation stations; only the \emph{increment} vs.\ the same planform untwisted is added. Stall becomes first-strip $C_{L,\max}$, and cannot exceed the untwisted 3D cap.

\begin{examplebox}
\textbf{Example --- why the search refused washout.}
On $\lambda = 0.4$ (and on the current $\lambda \approx 0.60$) the spanload is already near-elliptical, $e$ is already at the 0.98 cap. Twist cannot raise $e$ further. It \emph{can} unload the tip (good for stall) but the first-strip rule and the profile-drag increment make cruise slightly worse. The current search parked washout at $\approx 0^\circ$. On a \emph{rectangular} wing, washout does raise $e$ ($0.90 \to \sim 0.95$), but flying a rectangle to get that twist benefit also adds tip chord, cells, mass, and drops AR. That package still lost on margin. The optimizer's message: \textbf{taper already bought the induced-drag win; do not pay mass for a second copy of the same win.}
\end{examplebox}

\subsection{Worked drag budget (current night cruise)}
\label{sec:dragbudget}

$m = 8.745\,\mathrm{kg}$, $V = 11.42\,\mathrm{m/s}$ ($1.3 V_s$ binds), $\rho = 1.048$, $q = 68.3\,\mathrm{Pa}$, $S = 1.636\,\mathrm{m^2}$.

\begin{center}
\begin{tabular}{@{}lrrr@{}}
\toprule
 & $C_L$ / $C_D$ & Drag [N] & Share \\
\midrule
Net airplane $C_L$ & 0.768 & & \\
Wing $C_L$ & 0.784 & & \\
H-stab $C_L$ & $-0.109$ & & \\
Wing profile (S4310, $\mathrm{Re}_{\bar{c}}\approx 1.84\times 10^5$) & $C_{D_p}=0.0123$ & 1.38 & 44\% \\
Wing induced ($e=0.98$) & $C_{D_i}=0.0094$ & 1.05 & 33\% \\
H-stab profile & & 0.20 & 6\% \\
H-stab induced ($e_H=0.70$) & & 0.018 & 1\% \\
V-stab profile ($C_L=0$) & & 0.14 & 4\% \\
Pods & & 0.17 & 5\% \\
Booms ($\varnothing 25\,\mathrm{mm}$, $L=1.87\,\mathrm{m}$) & & 0.11 & 4\% \\
Control-surface gaps & & 0.10 & 3\% \\
\midrule
\textbf{Total} & $C_D=0.0283$ on $S$ & \textbf{3.16} & \\
Aero power $DV$ & & \textbf{36.1 W} & \\
$L/D$ & 27.1 & & \\
\bottomrule
\end{tabular}
\end{center}

\begin{intuition}
\textbf{Read this table like a designer, not an aerodynamicist showing off.} About 77\% of cruise drag is the wing. Profile now beats induced (44\% vs.\ 33\%) because the airplane is lighter and is forced to fly $1.3 V_s$ instead of aero min-power. Unconstrained min-power is $\sim$9.2\,m/s and $DV \approx 29\,\mathrm{W}$; the speed floor costs about $7\,\mathrm{W}$ of aero and $\sim$10\,W of bus. The entire empennage plus pods plus booms plus gaps is $\sim$0.74\,N. Polishing boom fairings will not close a 158\,Wh night gap. The remaining polar levers at fixed mass are $C_{L,\max}$ (or relaxing $1.3\to 1.2$) and wing profile $C_D$. Span and $e$ are already maxed.
\end{intuition}

Aero power 36\,W is \emph{not} night bus power. The propeller, motor, ESC, and the 5\,W avionics sit between $DV$ and the battery. That chain currently turns 36\,W of aero into $70.2\,\mathrm{W}$ of propulsion plus $5\,\mathrm{W}$ avionics $= 75.2\,\mathrm{W}$ on the bus. Propulsion, not the polar, is where most of the remaining watts live.

\begin{figure}[htbp]
  \centering
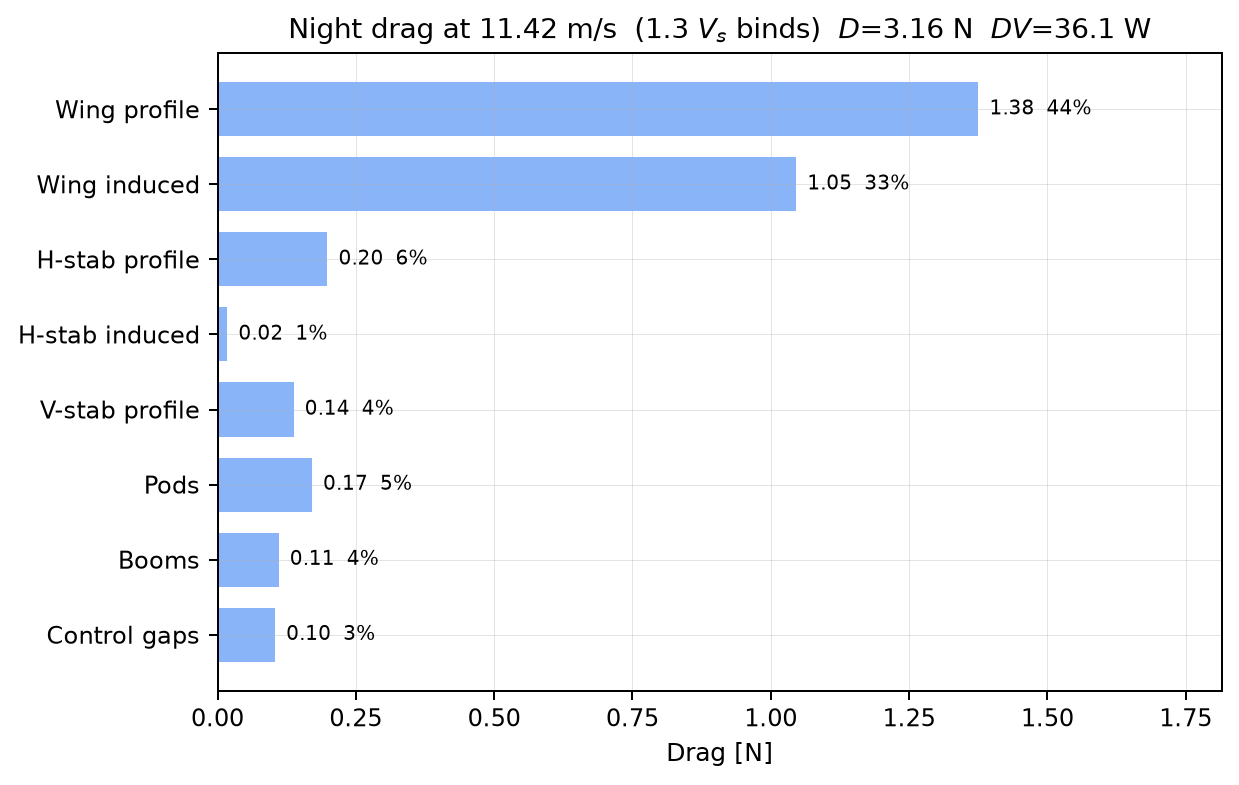
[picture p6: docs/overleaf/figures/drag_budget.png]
  
  \caption{Night drag budget at the flown speed $1.3 V_s = 11.42\,\mathrm{m/s}$. Wing profile 44\%, induced 33\%. Empennage plus pods, booms, and gaps is the remaining quarter.}
  \label{fig:drag}
\end{figure}

\begin{figure}[htbp]
  \centering
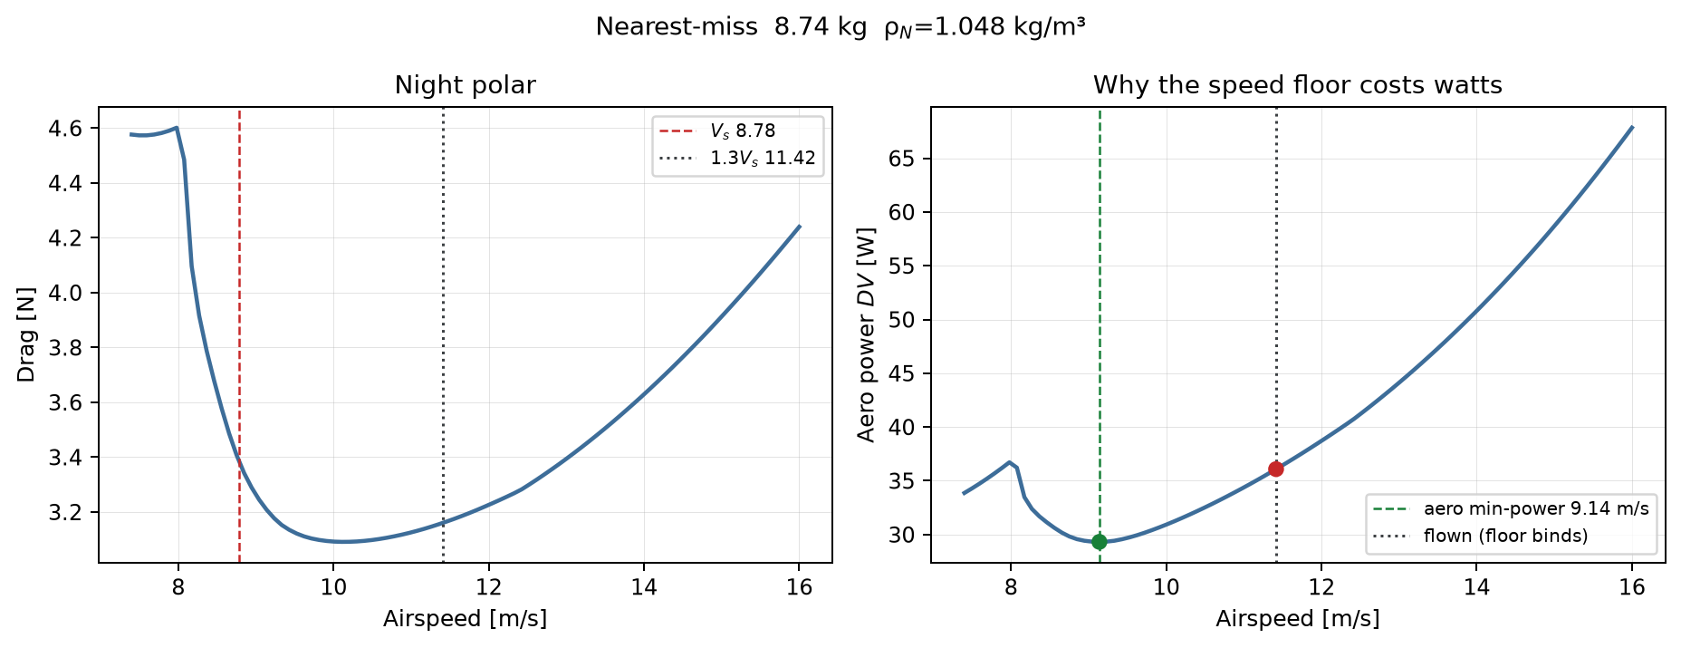
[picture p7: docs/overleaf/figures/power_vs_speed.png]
  
  \caption{Night polar and $DV(V)$. Unconstrained aero min-power is $\sim$9.2\,m/s ($DV\approx 29\,\mathrm{W}$). The $1.3 V_s$ floor binds at $11.42\,\mathrm{m/s}$ and costs about $7\,\mathrm{W}$ of aero / $\sim$10\,W of bus.}
  \label{fig:power-speed}
\end{figure}

% =====================================================================
\section{Solar array}
% =====================================================================

Files: \code{solar\_uav/environment.py}, \code{solar\_uav/components/solar\_array.py}.

\subsection{Sun}

pvlib Ineichen clear-sky at the site, minute resolution. The array is \textbf{horizontal} (wing top). Angle of incidence equals the solar zenith angle.

Plane-of-array irradiance before cells:

\begin{equation}
  E_\mathrm{POA}
    = \underbrace{E_\mathrm{DNI}\cos\zeta \cdot \mathrm{IAM}(\zeta)}_{\text{beam, with reflection}}
    + \underbrace{0.95\, E_\mathrm{DHI}}_{\text{diffuse IAM \flag{}}}.
\end{equation}

Then encapsulation transmission 0.97 \flag{}:

\begin{equation}
  E_\mathrm{eff} = 0.97\, E_\mathrm{POA}.
\end{equation}

IAM is pvlib's physical air/glass model. A horizontal wing at El Mirage ($34.65^\circ\mathrm{N}$) never sees the sun overhead except near noon in June, and even then $\zeta \ne 0$ most of the day. That cosine is the main reason ``battery night'' is longer than civil night.

\subsection{Cell temperature}

No flight-cooling credit. NOCT-style

\begin{equation}
  T_\mathrm{cell} = T_\mathrm{amb} + k\, E_\mathrm{eff},
\end{equation}

with $k$ calibrated so solstice-noon static $T_\mathrm{cell} = 75^\circ\mathrm{C}$ (user requirement). Ambient is a sinusoid, min at 05:00, max at 15:30, between 24 and $40^\circ\mathrm{C}$.

\subsection{Electrical output}

C60 bin I \flag{}: $P_\mathrm{mp} = 3.40\,\mathrm{W}$ at STC. Temperature coefficient $\gamma = -0.32\%/^\circ\mathrm{C}$. Wiring / mismatch / soiling 0.965 \flag{}. MPPT 0.95.

\begin{equation}
  P_\mathrm{bus}
    = N_\mathrm{cells}\, P_\mathrm{mp}
      \frac{E_\mathrm{eff}}{1000}
      \bigl[1 + \gamma (T_\mathrm{cell}-25)\bigr]
      \times 0.965 \times 0.95.
\end{equation}

\subsection{String voltage and power (GVB-8)}

The GVB-8 input range is $0$--$60\,\mathrm{V}$ and it charges a 25\,V bus from a panel that may sit above or below that bus (buck and boost). The old rule ``string Voc must stay below the depleted 6S bus so the converter can always boost'' is therefore dropped. Remaining datasheet caps, evaluated conservatively:

\begin{equation}
  N_{\max} = \min\left(
    \left\lfloor \frac{50}{V_\mathrm{oc}(10^\circ\mathrm{C})} \right\rfloor,
    \left\lfloor \frac{210\,\mathrm{W}}{P_\mathrm{mp,STC}} \right\rfloor
  \right)
  = \min(70, 61) = 61
\end{equation}

on bin I ($V_\mathrm{oc}(10^\circ\mathrm{C})\approx 0.713\,\mathrm{V}$, $P_\mathrm{mp}=3.40\,\mathrm{W}$). The 210\,W recommended panel power binds first. A bay that wants more than 61 cells still needs a second string (extra MPPT mass) or it is illegal under one-string-per-bay.

\begin{examplebox}
\textbf{Example --- extra cells lost.} A mixed-pack rectangular wing with 92--104 cells and extra strings was tried (``just put more solar on''). AR fell to $\sim$16.7, mass rose $\sim$1.4\,kg, night watts rose, and margin got \emph{worse} (about $-184\,\mathrm{Wh}$ vs.\ $-160\,\mathrm{Wh}$ on the tapered 82-cell wing, at the old 410\,g/m booms). Noon already spills. The night does not care that you had 20 more cells at 13:00. It cares that you are heavier and draggier at 02:00.
\end{examplebox}

\begin{figure}[htbp]
  \centering
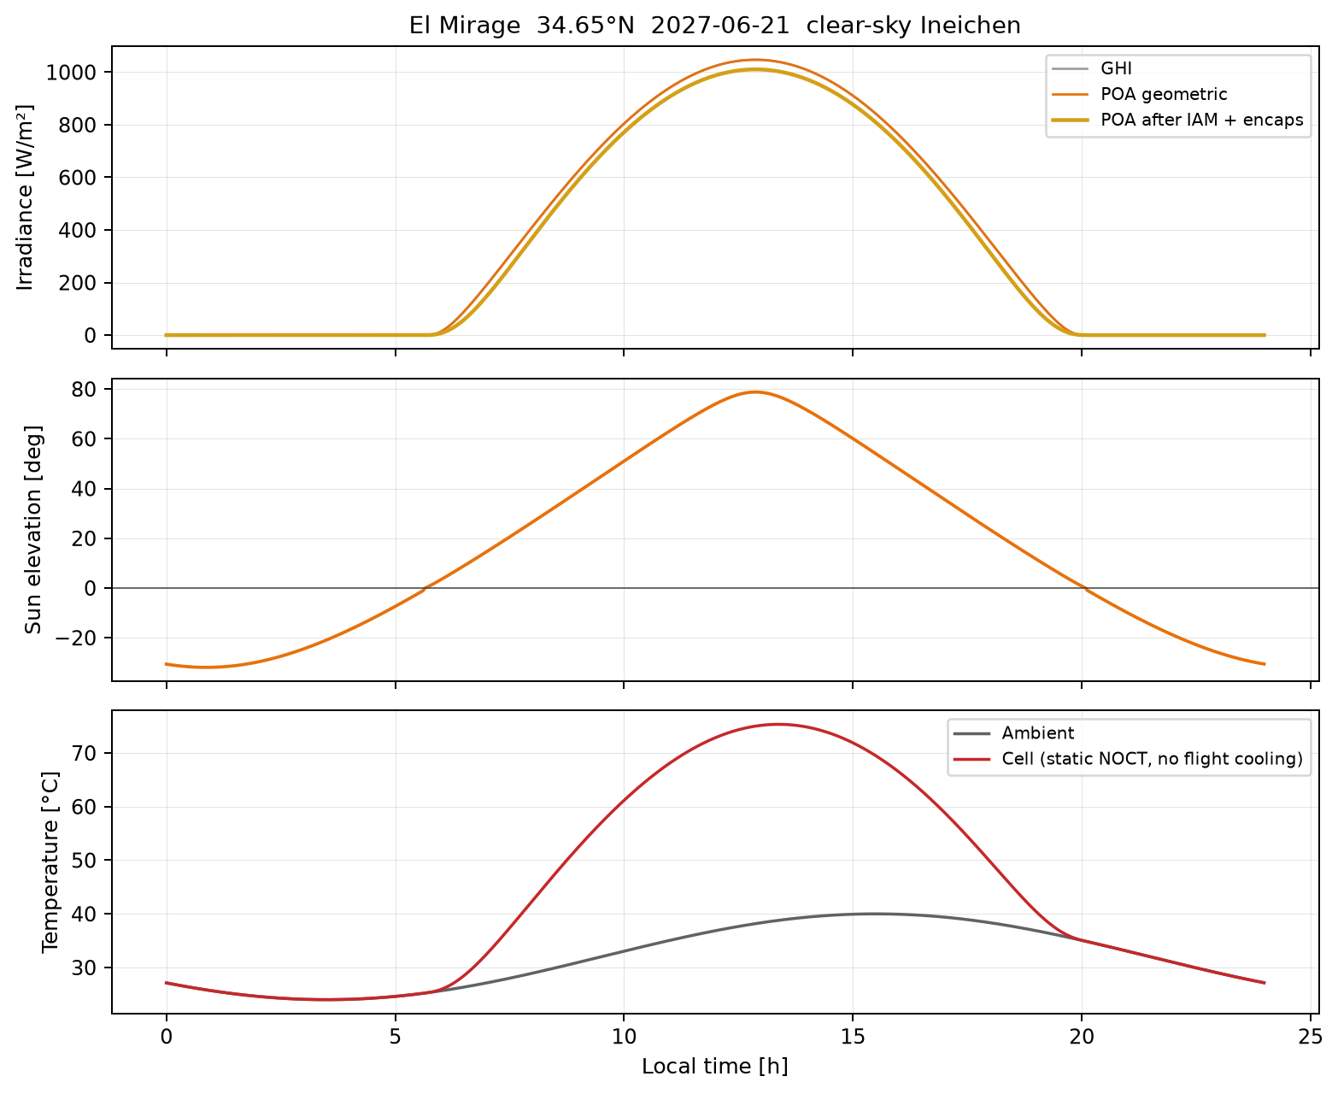
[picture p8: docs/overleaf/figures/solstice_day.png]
  
  \caption{El Mirage solstice design day: Ineichen GHI and plane-of-array after IAM and encapsulation, sun elevation, and the hot static cell-temperature model (no flight-cooling credit). Peak cell $T$ is calibrated to $75^\circ\mathrm{C}$.}
  \label{fig:solstice}
\end{figure}

% =====================================================================
\section{Battery}
% =====================================================================

File: \code{solar\_uav/components/battery.py}.

Two GOLD V1 packs in parallel: 483\,Wh, 23.68\,Ah, 1.278\,kg, 6\,A charge, 313\,W sustained discharge each. Usable energy at the 20\% floor:

\begin{equation}
  E_\mathrm{usable} = 2 \times 483 \times 0.80 = 773\,\mathrm{Wh}.
\end{equation}

SOC is energy-based. Open-circuit voltage is a generic Si-anode Li-ion curve \flag{}, 3.0--4.2\,V/cell, times 6. Internal resistance $45\,\mathrm{m}\Omega$ per pack \flag{}, paralleled.

Terminal power during discharge: $P = V_\mathrm{oc} I - I^2 R$. Chemistry energy removed is $V_\mathrm{oc} I \Delta t$ (you pay $I^2R$ from the bus but it does not come out of SOC as extra capacity --- it is a conversion loss). Charge is the reverse, capped at 6\,A/pack, with a CV taper as $V_\mathrm{oc}$ approaches 25.2\,V.

The march \emph{allows} SOC to fall through 20\% so we can measure how far a miss is. Closure still requires staying above 20\%.

\begin{figure}[htbp]
  \centering
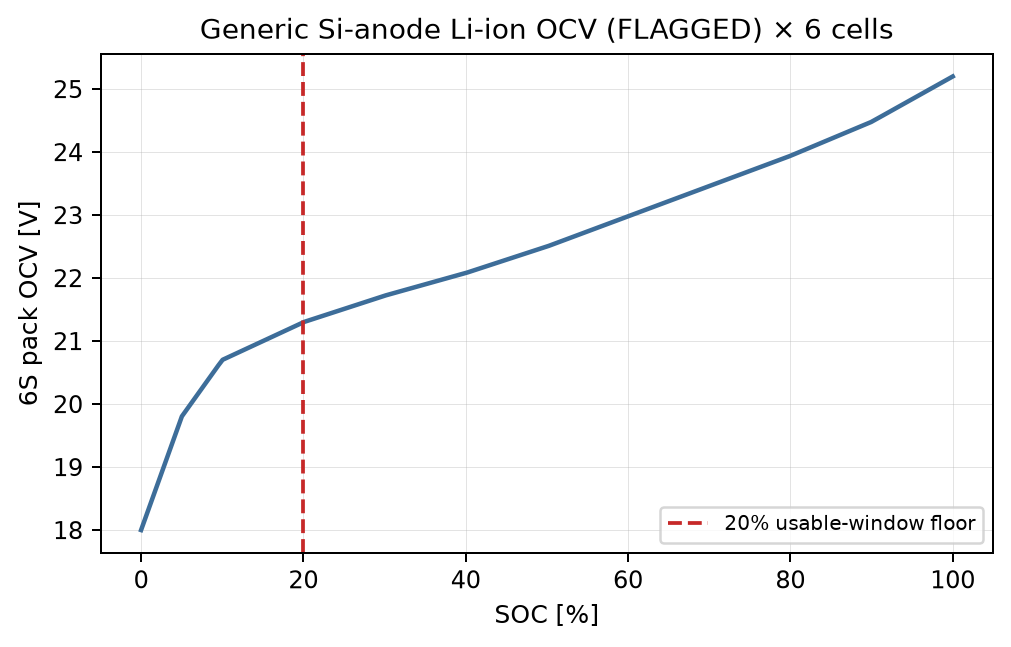
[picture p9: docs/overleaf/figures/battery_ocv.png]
  
  \caption{FLAGGED generic Si-anode OCV curve, times 6. The 20\% floor is the same 80\% usable window as the 773\,Wh pack budget.}
  \label{fig:ocv}
\end{figure}

% =====================================================================
\section{The 24-hour energy march}
% =====================================================================

File: \code{solar\_uav/mission.py}. Default step: 5 minutes.

Night and day bus loads are each a single number: propulsion at that density's min-power speed, plus 5\,W avionics. Then, at every timestep,

\begin{align}
  \text{is\_night} &= (P_\mathrm{solar} < P_\mathrm{night}), \\
  P_\mathrm{load} &= \begin{cases}
      P_\mathrm{night} & \text{if night}, \\
      P_\mathrm{day} & \text{if day},
    \end{cases} \\
  P_\mathrm{net} &= P_\mathrm{solar} - P_\mathrm{load}.
\end{align}

\begin{warningbox}
\textbf{Do not mentally replace $P_\mathrm{net}$ with $-P_\mathrm{night}$ at dusk.} If the array is making 60\,W and the load is 75\,W, the pack only supplies 15\,W. Calling that ``night'' and draining 75\,W is how people convince themselves the physics is worse than it is --- and then over-correct with a third pack. The code already counts the shoulders.
\end{warningbox}

The march starts at the \textbf{last afternoon timestep} where $P_\mathrm{net} > 1\,\mathrm{W}$, with SOC $= 1$ (launch / ground charge), wraps 24 hours, then repeats that wrap \textbf{without resetting the pack}. Day 2 is the scored loop: the night is fully counted, and we test that Tuesday is not poorer than Monday.

\textbf{Battery-true night} is hours with $P_\mathrm{solar} < P_\mathrm{night}$. On 21 June at El Mirage ($34.65^\circ\mathrm{N}$) that is \textbf{14.0 hours} on the current airplane, not the $\sim$9.5 hours of civil night. A horizontal wing at this latitude simply does not make cruise power at low sun.

\begin{examplebox}
\textbf{Example --- why ``75\,W $\times$ 14\,h = 1050\,Wh, we need another pack'' is the wrong arithmetic.}
Usable pack is 773\,Wh. Shoulders (dawn/dusk when the array makes some but not all of cruise) contribute on the order of 100+\,Wh that a naive $P\times t$ ignores. The honest integral is still larger than 773\,Wh --- that is why we miss. On the repeating day the nearest-miss bottoms at $\mathrm{SOC}=0.007$ with a $-28\,\mathrm{Wh}$ cycle. Closing is ``about 11\,W off the night bus'' or ``a bit more pack,'' not ``the polar must be twice as good.''
\end{examplebox}

\begin{figure}[htbp]
  \centering
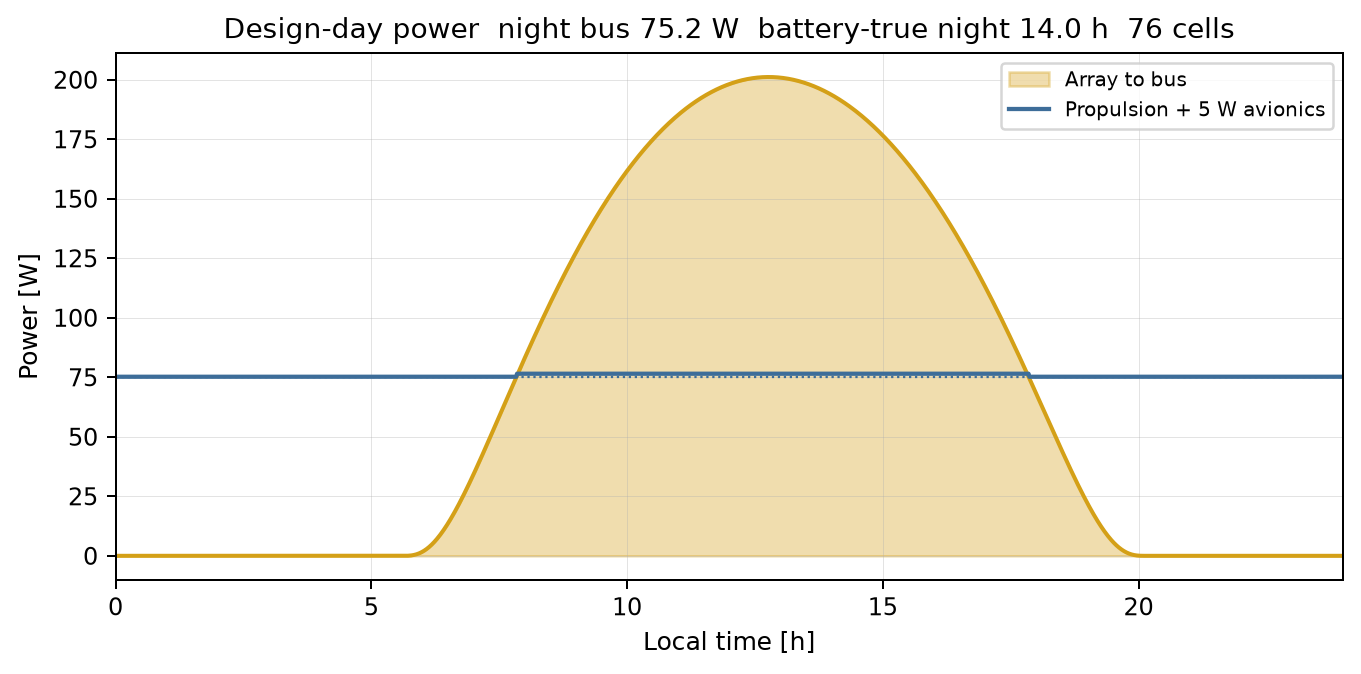
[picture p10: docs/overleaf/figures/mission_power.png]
  
  \caption{Local-time power on 21 June. Array peaks near $200\,\mathrm{W}$; cruise is $75\,\mathrm{W}$. Battery-true night is the 14.0\,h where the gold curve is below the blue load, not civil sunset-to-sunrise.}
  \label{fig:mission-power}
\end{figure}

\begin{figure}[htbp]
  \centering
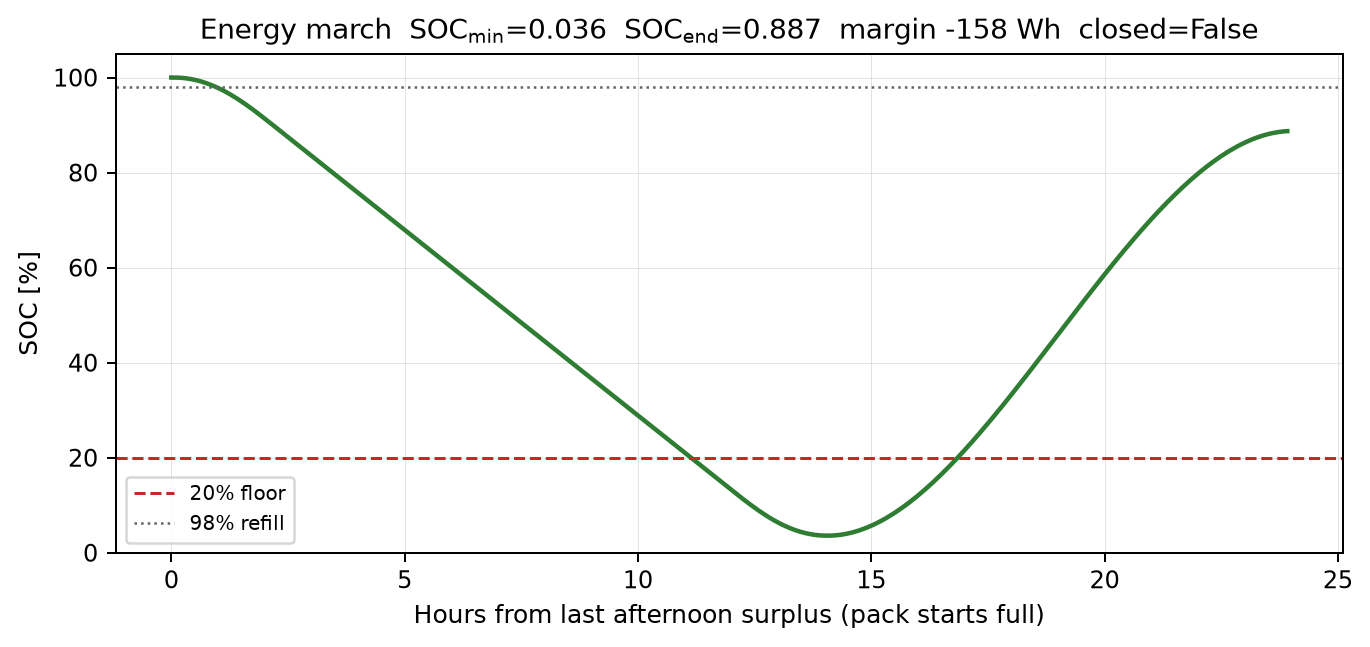
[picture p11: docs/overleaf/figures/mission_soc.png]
  
  \caption{Two-day march: launch full at the last afternoon surplus, then score day 2. On the repeating day the nearest-miss bottoms at $\mathrm{SOC}=0.007$ and still ratchets. Unmet energy appears on day 2 once the first-night gift is spent.}
  \label{fig:mission-soc}
\end{figure}

% =====================================================================
\section{Propulsion}
\label{sec:propulsion}
% =====================================================================

Files: \code{solar\_uav/components/propeller.py}, \code{mejzlik.py}, \code{motor.py}, \code{propulsion.py}.

Two motors, two props, thrust split equally. 6S bus, nominal 22.2\,V, climb uses 25.2\,V.

\subsection{Propeller maps}

APC PER3 files (vortex theory) and Mejzlik 2-blade electric maps (in-house BEM / vortex). Both are \textbf{computational, not measured}. Uncertainty factors, applied in \code{PropulsionSystem} (not inside a \code{nominal=True} table read):

\begin{equation}
  T_\mathrm{used} = 0.92\, T_\mathrm{map}, \qquad
  P_\mathrm{used} = 1.08\, P_\mathrm{map}
  \quad \text{\flag{}}.
\end{equation}

Level flight asks the map for $T_\mathrm{need}/0.92$ so the derated thrust still equals drag.

Nondimensional definitions (McCormick / MIT 16.unified):

\begin{equation}
  J = \frac{V}{n D}, \qquad
  T = C_T(J)\, \rho n^2 D^4, \qquad
  P = C_P(J)\, \rho n^3 D^5, \qquad
  \eta = \frac{J C_T}{C_P}.
\end{equation}

$n$ is rev/s, $D$ is diameter in metres. $C_T$ and $C_P$ come from the published map. Density scaling of a tabulated $T,P$ is $\rho/\rho_\mathrm{ref}$ with $\rho_\mathrm{ref} = 1.225\,\mathrm{kg/m^3}$ for APC.

\textbf{Query rule, in order:}

\begin{enumerate}
  \item If this airspeed exists on an RPM block of the table, interpolate $T(\mathrm{RPM})$ at that speed, density-scale, and pick the RPM that makes the required thrust. \emph{If the slowest tabulated RPM that covers this speed already makes enough thrust, stop. Do not slow down further.}
  \item Otherwise fall back to $C_T(J)$ similarity, but only for $J < J_\mathrm{windmill}$ (the advance ratio where $C_T$ crosses zero). Past windmill the blade is a drag device; there is no cruise solution there.
  \item If table and similarity disagree by more than 15\% (\code{PROP\_SANITY\_REL}), raise a \flag{} on the result. The mission still uses the table value when the table was the source.
\end{enumerate}

\begin{warningbox}
\textbf{The $n^2$-scaling bug, as a worked example.}
At fixed $V$, a naive ``I only need a tiny thrust, scale RPM with $\sqrt{T}$'' walks $J = V/(nD)$ \emph{up}. For the APC $22\times12$E, zero-thrust is near $J \approx 0.67$. Night cruise at 10.7\,m/s wants $n \approx 2070$\,RPM ($J \approx 0.58$) on the table. Scaling down to 1190\,RPM puts $J \approx 1.14$, past windmill. Similarity then says $T=0$. The interpolator had been reporting a few newtons and $\sim$62\,W anyway. That is how a closed design appeared out of nothing. The rule ``never $n^2$-scale RPM down at fixed speed once a covering block exists'' exists so this cannot happen again.
\end{warningbox}

\begin{intuition}
\textbf{Intuition for $J$.} $J$ is ``how much air is rushing at the prop compared to how fast the blades are spinning.'' Small $J$: hovering / climb, blades see mostly rotation, lots of thrust, lots of power. Large $J$: the airplane has run out in front of the blades; they start to windmill. A high-pitch ``cruise prop'' reaches windmill later (larger $J$), which is why we shortlist pitch ratios $0.40$--$0.85$. Even then, a 21$\times$14 at 10.5\,m/s and 1545\,RPM is at $J \approx 0.76$, and Mejzlik similarity says $C_T \approx 0$ while the table still lists $\sim$1.8\,N per blade --- that is why older nearest-misses on MJ-21$\times$14EL were on the optimistic side of the table. The current airplane flies an APC $16\times12$E at 11.42\,m/s and 2365\,RPM; the FLAG there is shaft power, table $28.0\,\mathrm{W}$ vs.\ similarity $22.8\,\mathrm{W}$ (19\%). Night watts use the table. The FLAG is in the CSV for a reason.
\end{intuition}

\subsection{Motor and ESC}

First-order DC motor. Datasheet $K_v$, $R_i$, $I_0$ at 8.4\,V. Torque constant $K_t = 1 / K_{v,\mathrm{rad}}$. Gearbox (if any) ratio $g$, efficiency 0.96 \flag{}. Direct drive pays no gearbox loss.

Given propeller torque $Q_p$ and RPM $n_p$:

\begin{align}
  Q_m &= \frac{Q_p}{g\,\eta_\mathrm{gear}}, \qquad
  n_m = n_p\, g, \\
  I &= \frac{Q_m}{K_t} + I_0, \\
  V &= I R_i + \frac{n_m}{K_v}, \\
  P_\mathrm{bus,1} &= \frac{V I}{\eta_\mathrm{ESC}}.
\end{align}

$I_0$ is still paid when loaded --- it is iron + friction, not ``only at idle.'' Two motors: $P_\mathrm{bus} = 2 P_\mathrm{bus,1}$. A point with $V > 22.2\,\mathrm{V}$ is infeasible at cruise (climb is allowed to 25.2\,V).

$\eta_\mathrm{ESC} = 0.95$ \flag{}. The code does \emph{not} currently inflate that loss when duty is below 50\%, but \code{ESC\_DUTY\_MIN = 0.50} exists as a documented warning. On the current 12L + $16\times12$E at night, $V \approx 6.0\,\mathrm{V}$ at 2365\,RPM, i.e.\ duty $\sim$27\% on a 22.2\,V pack. \textbf{Real ESC efficiency at that duty is worse than 95\%.} Treating 0.95 here is an optimistic FLAG on night bus. A rewind to $K_v \approx 180$--$220$ would put duty at or above 50\%; at fixed $(Q,\mathrm{RPM})$ the 12L rewind model says cruise bus watts are nearly independent of $K_v$, so the catalog kv410 is not a modelled watt win.

\begin{intuition}
\textbf{Intuition for $I = Q/K_t + I_0$.} $Q/K_t$ is the current that actually makes torque. $I_0$ is the current the motor drinks just to spin itself --- hysteresis, windage, bearings. At climb, $Q/K_t$ dwarfs $I_0$ and you barely notice. At night cruise the torque is tiny, so $I_0$ is a large fraction of the bill. That is why a high-$I_0$ motor can look fine on a power-limit datasheet and still lose the night.
\end{intuition}

\subsection{Free-$K_v$ rewind model}

Not a catalog part. Same A40-12L stator, $R_i \propto 1/K_v^2$, $I_0 \propto K_v$. Used to decide what $K_v$ to shop for. At fixed $(Q, n)$, cruise bus power is nearly independent of $K_v$ once you are voltage-feasible --- winding changes trade voltage for current. The 12L wins against the geared 10L because of \textbf{$I_0$ and gearbox loss}, not because 410\,rpm/V is magic.

\subsection{Motors evaluated}
\label{sec:motors}

Catalog in \code{MOTOR\_CATALOG}:

\begin{center}
\begin{tabular}{@{}lrrrrrr@{}}
\toprule
Name & $K_v$ & $R_i$ [$\Omega$] & $I_0$ [A] & $g$ & Mass [kg] & $P_\max$ [W] \\
\midrule
A40-10L V2 kv1100 + 6.7:1 PG & 1100 & 0.019 & 1.70 @ 8.4\,V & 6.7 & 0.315 & 2200 \\
A40-10S V4G kv1600 + 6.7:1 PG & 1600 & 0.012 & 2.75 @ 8.4\,V & 6.7 & 0.247 & 1500 \\
A40-12L V4 kv410 direct & 410 & 0.039 & 1.04 @ 8.4\,V & 1.0 & 0.275 & 1100 \\
\bottomrule
\end{tabular}
\end{center}

Plus the rewind grid $K_v = 180, 200, \ldots, 900$ on the 12L stator (direct drive).

\begin{examplebox}
\textbf{Example --- why 12L beat 10L.}
The 10L is the Hacker ``gliders to 14\,kg, props to 23\,in'' recommendation. It is \emph{not} the search default. At night the prop wants $\sim$1500--2000\,RPM and a few tenths of a newton-metre. After the 6.7:1 gearbox the \emph{motor} is spinning at 10--13\,kRPM and still paying $I_0 = 1.7\,\mathrm{A}$ plus 4\% gearbox. The 12L's $I_0 = 1.04\,\mathrm{A}$ is at the shaft RPM you actually want, with no gearbox. Climb on the 12L + $16\times12$E is still $\sim$15\,m/s. The 10S is worse still ($I_0 = 2.75\,\mathrm{A}$). \textbf{Mindset: size the motor for night $I_0$ and map bite, not for takeoff marketing.}
\end{examplebox}

\subsection{Propellers evaluated}
\label{sec:props}

Shortlist rule (\code{shortlist\_props}):

\begin{itemize}
  \item APC style containing ``E'' (electric), excluding MR, SF, W, N, F2B, 3-blade, 4-blade.
  \item Mejzlik 2-blade electrics (style contains E).
  \item Diameter $\ge 16\,\mathrm{in}$ (no upper cap; climb + cruise decide).
  \item Pitch / diameter $\in [0.40, 0.85]$.
\end{itemize}

That is \textbf{51} maps. Full list in Appendix~\ref{app:props}.

Neighborhood searches used a 7-prop subset that had already survived earlier ranks:

\begin{center}
\texttt{MJ-21x14EL}, \texttt{16x12E}, \texttt{17x12E}, \texttt{18x12E},
\texttt{19x12E}, \texttt{20x13E}, \texttt{21x13E}.
\end{center}

The inner loop currently picks \texttt{16x12E} on the 12L nearest-miss. Larger tabulated diameters cost night watts on-map; similarity-filled points (e.g.\ a $20\times15$E off the table) are excluded. Mejzlik 21-inch fans still appear in the shortlist and in older CSVs, but they are not the current pick.

APC thin-electric mass (when not in a catalog) is the fit $m = 0.263\times 10^{-3}\, D_\mathrm{in}^{1.96}$ \flag{}.

% =====================================================================
\section{Current nearest-miss (does not close)}
% =====================================================================

From \code{outputs/phase4\_candidates.csv} (812 scored, 0 closed), best row of the 17 August 2026 search after independent tails, $0.8\times$ wing areal mass, and 1\,in / $0.174\,\mathrm{kg/m}$ booms. Those numbers are also \code{REF\_*} in \code{config.py} for the visualizer. Washout chose $\approx 0^\circ$.

\begin{center}
\begin{tabular}{@{}ll@{}}
\toprule
Item & Value \\
\midrule
Motor & A40-12L V4 kv410 direct \\
Prop & APC $16\times12$E \\
Wing & $5.907\times 0.314\,\mathrm{m}$, $\lambda=0.598$ from 0.275 of the outboard \\
Area / AR / $e$ & $1.636\,\mathrm{m^2}$, 21.3, 0.98 (cap) \\
H-stab / V-stab arm & $1.278\,\mathrm{m}$ / $1.696\,\mathrm{m}$ (V LE $0.19\,\mathrm{m}$ behind H TE) \\
Boom spacing / elevator & $1.133\,\mathrm{m}$ / 34\% chord \\
$V_H$ actual / $V_V$ & $0.687$ (packing chord floor) / $0.030$ \\
H-stab height / downwash $k$ & $z_H=0$ (wing plane) / $k_\varepsilon=1.21$ (VLM $>$ handbook) \\
Static margin & 43\% MAC \\
Array & 76 cells, strings $26+26+16+8$ (4 MPPTs) \\
Mass & $8.745\,\mathrm{kg}$ (booms $1.868\,\mathrm{m}$, $\varnothing 25.4\,\mathrm{mm}$) \\
Night / day bus & $75.2\,\mathrm{W}$ / $76.5\,\mathrm{W}$ (includes 5\,W avionics) \\
$V_\mathrm{stall}$ / $V_\mathrm{night}$ & $8.78$ / $11.42\,\mathrm{m/s}$ ($1.3 V_s$ binds) \\
Climb & $14.8\,\mathrm{m/s}$ (requirement 1.5) \\
Battery-true night & 14.0\,h \\
$\mathrm{SOC}_\mathrm{min}$ / $\mathrm{SOC}_\mathrm{end}$ & 0.036 / 0.887 \\
Margin & $\mathbf{-158\,\mathrm{Wh}}$ \\
Closed? & No \\
\bottomrule
\end{tabular}
\end{center}

Mass lumps (kg): batteries 2.56, wing 2.25, fixed 1.20, booms 0.65, solar 0.61, motors 0.55, MPPTs 0.43, H-stab 0.22, V-stabs 0.15, props 0.12.

The same search family is lighter than the old 1.5\,in / $0.290\,\mathrm{kg/m}$ $\pi$-tail nearest-miss ($\sim$9.8\,kg, $-112\,\mathrm{Wh}$ at a slower $V_\mathrm{night}$). Independent $\ell_v$, thinner booms, and the $0.8\times$ wing cut mass, but El Mirage density plus the $1.3 V_s$ floor put night bus back at 75\,W and the SOC floor at 0.036. Still about 11\,W of night bus short of the 20\% floor, before you even discount the prop-map and ESC-duty FLAGs.

Prop FLAG on this row: at 2365\,RPM, 11.42\,m/s, table shaft $28.0\,\mathrm{W}$ vs.\ similarity $22.8\,\mathrm{W}$ (19\%). Night watts use the table. ESC duty is $\sim$27\%; the 95\% ESC efficiency is optimistic.

\begin{figure}[htbp]
  \centering
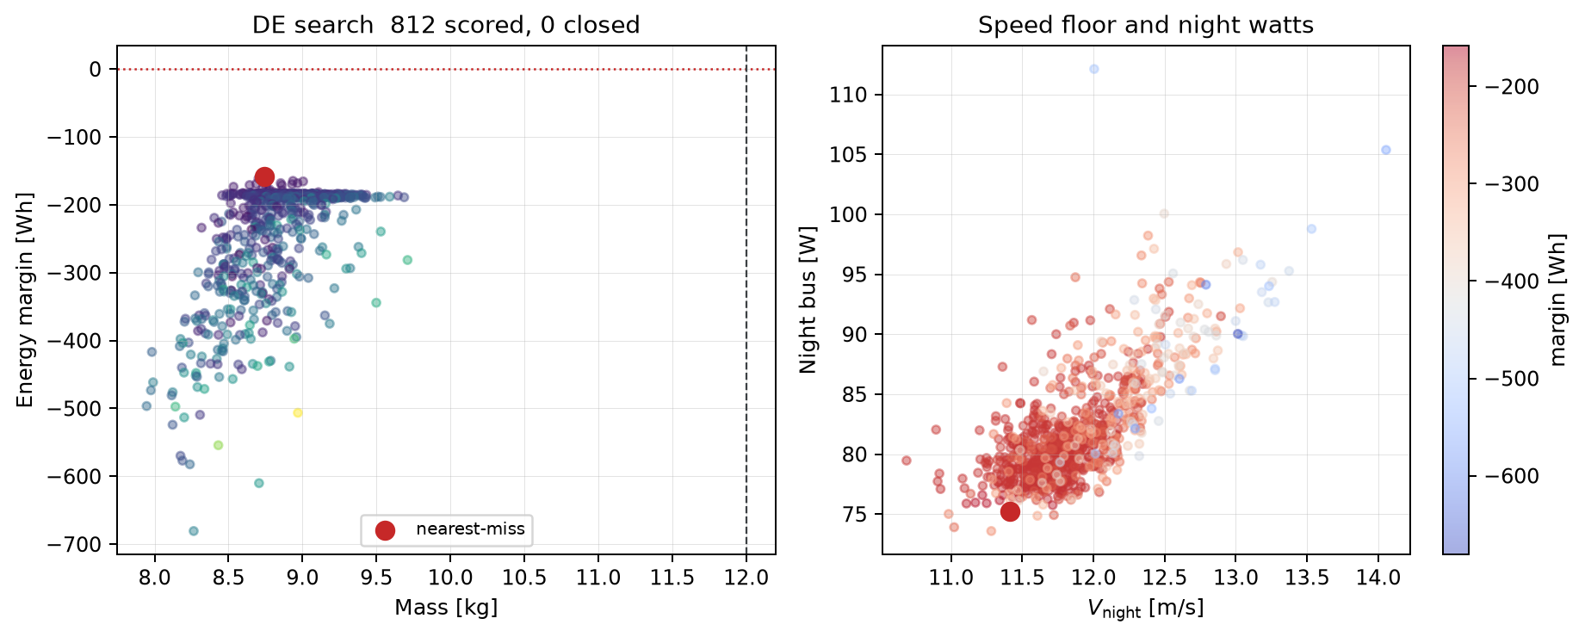
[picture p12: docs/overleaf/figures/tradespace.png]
  
  \caption{812 scored DE candidates, none closed. Colour on the left is night bus; on the right is margin. The nearest-miss (red) is the lightest / slowest / lowest-watt corner that still packs a legal array. The 12\,kg MTOW wall is unused.}
  \label{fig:tradespace}
\end{figure}

% =====================================================================
\section{Top learnings: design priority and mindset}
% =====================================================================

These are not slogans. They are what the model has already spent compute to tell us.

\subsection{Night is the only constraint that is close}

Day array $\sim$200\,W vs.\ $\sim$75\,W cruise. Climb is an order of magnitude above requirement. MTOW has $\sim$3\,kg of unused budget on the nearest-miss. Span is at the wall. The SOC floor on the repeating day is what fails. \textbf{Every other subsystem is a servant of night bus watts and night duration.}

\subsection{Mass and induced drag beat parasite tricks}

Equation~\eqref{eq:cdi} with $C_L \propto W/S$ means

\begin{equation}
  D_i \propto \frac{W^2}{\rho V^2 b^2 e}.
\end{equation}

Span is maxed. $e$ is capped. At \emph{fixed} mass the remaining polar lever is the $1.3 V_s$ speed floor (true aero min-power is $\sim$9.2\,m/s). If mass is still free, a kilogram of boom is not ``structure we can live with''; it is $C_L$ we fly for 14 hours. Fairings, trip dots, and boom $\varnothing$ are a few percent of drag. Do not spend the team's year there until night bus is honest and the structure is light.

\subsection{The propeller map bite is bigger than the polar}

Aero power is 36\,W. Bus is 75\,W. The missing $\sim$39\,W is prop efficiency at cruise $J$, $I_0$, the 95\% ESC at 27\% duty, and the derate/inflate factors. Chasing 2\% on S4310 $c_d$ saves tenths of a watt of aero. Putting the blade on a tabulated point with real $C_T$, or accepting that a fan is past windmill and picking another, moves tens of watts. The current $16\times12$E is already the best \emph{on-map} fan in the shortlist.

\subsection{Do not invent operating points}

If the map does not list a gentle cruise RPM at that speed, the airplane cannot have that cruise. Similarity past $J_\mathrm{windmill}$ is not a loiter mode. This is the single most expensive lesson in the repo.

\subsection{Taper first, cells second, washout last}

Taper $\lambda\approx 0.60$ from 0.28 of the outboard: fewer tip cells than a rectangle, AR 21.3, $e$ at the cap, Voc-legal strings. Older searches that dropped taper to glue more cells on the outboard made the night worse. Washout on the current wing is $\approx 0^\circ$. \textbf{Do not undo a planform that already matches the ellipse in order to print more silicon that spills at noon.}

\subsection{Motors: night $I_0$, not takeoff watts}

The 10L is the brochure motor. The 12L is the night motor. Climb still clears 1.5\,m/s by a huge margin ($\sim$15\,m/s on the $16\times12$E). Catalog kv410 is 27\% ESC duty; a rewind to $\sim$200\,rpm/V would make the 95\% ESC assumption honest without changing cruise watts in the rewind model. If a future motor has lower $I_0$ at 2000--2400\,RPM on 6S, that is worth more than another 100\,W of burst rating.

\subsection{Closing moves that actually scale}

Roughly 11\,W off night bus, or a third pack (currently forbidden), or array that produces cruise power at lower sun (camber / incidence of the cells, not more noon area). At fixed mass, raising $C_{L,\max}$ (or relaxing $1.3\to 1.2$) is the polar move that actually changes the speed you fly. T-tail downwash credits, $\pi$-tail endplate credits, and flight cooling of the cells are not those moves --- and they are conservative-physics violations if taken as free gains.

\subsection{Mindset}

\begin{itemize}
  \item Prefer an honest fail over an optimistic close.
  \item When two models disagree, take the worse number and write a FLAG, do not average them toward closure.
  \item Unused MTOW is not a license to add mass ``because we can.'' Mass is night watts.
  \item Unused climb is not a license to pick a thirstier motor ``because we have thrust.''
  \item Noon solar that spills is not endurance. Morning solar that covers cruise earlier \emph{is}.
\end{itemize}

% =====================================================================
\section{What this model does not do}
% =====================================================================

New members should not assume the following are in the physics:

\begin{itemize}
  \item 3D CFD, vortex-lattice of the full airplane, or measured glide polars (Phase 6 is the hook for those).
  \item Ground effect, banked turns, gusts, or a control-law simulation.
  \item Propeller--wing interference, swirl recovery, or blade-element theory we wrote ourselves.
  \item Measured ESC efficiency vs.\ duty; measured pack DCIR; measured cell temperature in flight.
  \item Structural sizing (spars are inside the areal density, not a beam model). No aeroelasticity.
  \item Weather other than clear-sky Ineichen. No clouds, no albedo from water, no horizon masking.
  \item Takeoff roll, landing, or a 89-hour trace with degrading packs --- only a two-day march (launch-full, then a repeating 24\,h loop).
  \item Payload, retracts, or a third pack (locked out).
\end{itemize}

Phase 5 (\code{monte\_carlo.py}) samples irradiance, cell temperature, array efficiency, mass growth, drag, prop factors, avionics, and pack energy, and reports $P(\mathrm{closure})$ and a tornado. It does not invent new physics; it shakes the FLAGGED knobs. Phase 6 is bench/flight protocols to replace those knobs with measurements.

% =====================================================================
\section{FLAGGED assumptions (complete working list)}
% =====================================================================

Grep \texttt{FLAGGED} in \code{solar\_uav/config.py} and the component modules. The important ones, with the conservative direction:
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

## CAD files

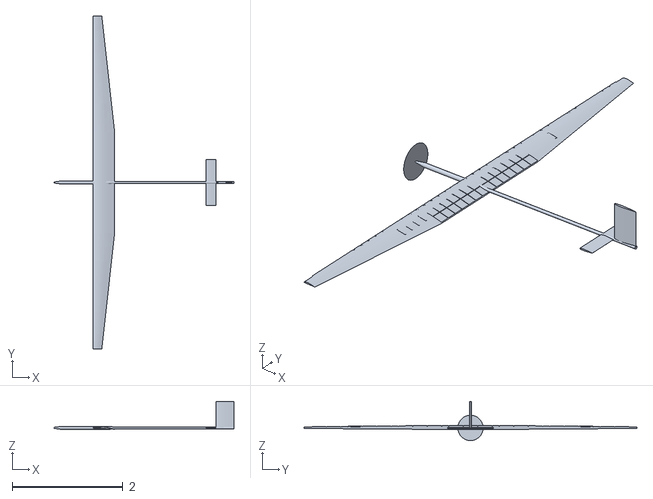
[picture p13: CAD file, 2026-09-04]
conventional/outputs/aircraft.stl
3.24 x 6.00 x 0.705

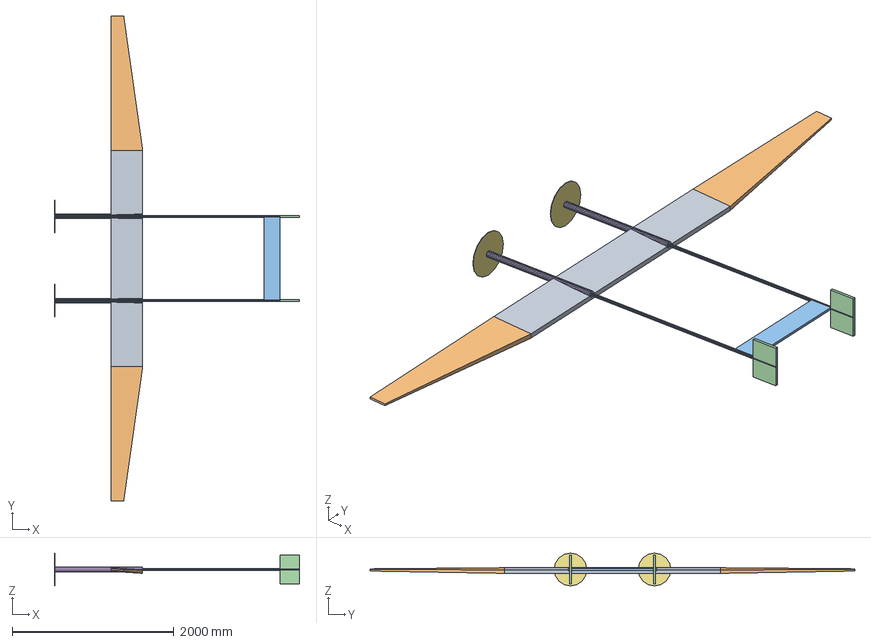
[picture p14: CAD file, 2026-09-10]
outputs/aircraft.step
3031.3 x 6000.0 x 406.4 mm

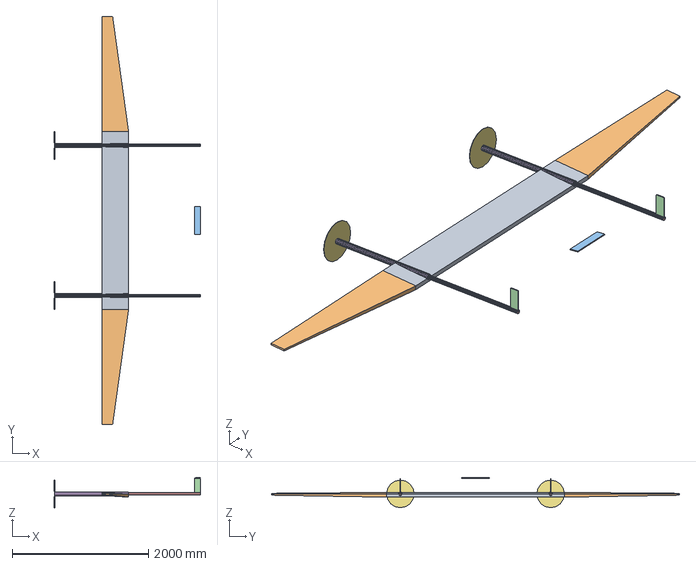
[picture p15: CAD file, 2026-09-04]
split_empennage/outputs/aircraft.step
2150.0 x 6000.0 x 447.4 mm

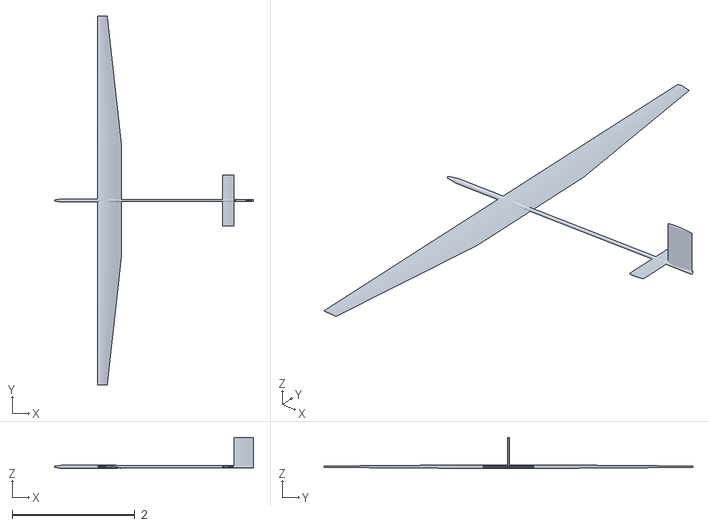
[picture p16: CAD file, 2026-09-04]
conventional/outputs/aircraft_structure.stl
3.24 x 6.00 x 0.505

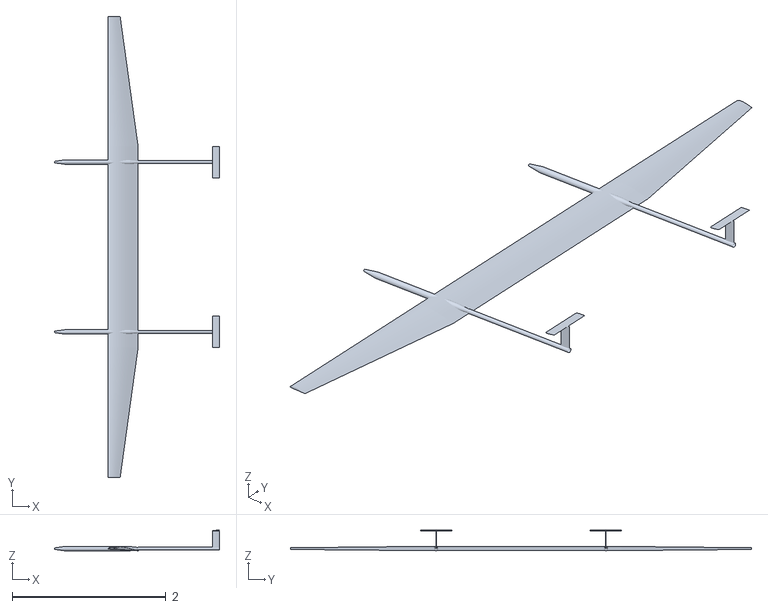
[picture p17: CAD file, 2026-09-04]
split_empennage/outputs/aircraft_structure.stl
2.15 x 6.00 x 0.268

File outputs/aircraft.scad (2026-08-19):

// Twin-boom solar UAV — generated from solar_uav.cad
// Units: metres. Open in OpenSCAD (F6 to render).
// Independent tails: H-stab in the wing plane, V-stabs straddle the boom.
// Boom: wing c/4 → V-stab root TE. Props 700 mm ahead of wing LE.
// Incidence from NeuralFoil: wing 3.83 deg, H-stab -0.15 deg (booms at α≈0).
$fn = 32;

module airfoil_sec(y, chord, pts) {
    translate([0, y, 0])
        rotate([90, 0, 90])
            linear_extrude(height=0.002, center=true)
                scale([chord, chord]) polygon(points=pts);
}

module wing_planform(pts) {
    // Rectangular carry-through (LE unswept), then optional outboard taper.
    if (abs(3.0000 - 3.0000) < 0.02) {
        rotate([90, 0, 90])
            linear_extrude(height=6.0000, center=true)
                scale([0.3100, 0.3100]) polygon(points=pts);
    } else {
        rotate([90, 0, 90])
            linear_extrude(height=6.0000, center=true)
                scale([0.3100, 0.3100]) polygon(points=pts);
        for (s = [-1, 1]) {
            hull() {
                airfoil_sec(s*3.0000, 0.3100, pts);
                airfoil_sec(s*3.0000, 0.3100, pts);
            }
        }
    }
}

module naca_tail(span, chord, pts) {
    rotate([90, 0, 90])
        linear_extrude(height=span, center=true)
            scale([chord, chord]) polygon(points=pts);
}

module vfin_sec(x, z, chord, pts) {
    // Thin airfoil slice in the X–Y plane at height z (chord along x).
    translate([x, 0, z])
        linear_extrude(height=0.002, center=true)
            scale([chord, chord]) polygon(points=pts);
}

module vstab_fin(pts) {
    hull() {
        vfin_sec(0, -0.2287, 0.3050, pts);
        vfin_sec(0, 0.2287, 0.3050, pts);
    }
}

module nacelle(y) {
    translate([-0.7000, y, 0])
        rotate([0, 90, 0])
            hull() {
                sphere(r=0.010);
                translate([0, 0, 0.1212])
                    sphere(r=0.0281);
                translate([0, 0, 1.0100])
                    sphere(r=0.0155);
            }
}

color([0.82, 0.84, 0.86])
    rotate([0, 3.8346, 0])
        wing_planform([[1.00000, 0.00000], [0.99665, 0.00043], [0.98675, 0.00184], [0.97069, 0.00444], [0.92202, 0.01351], [0.89054, 0.01984], [0.85507, 0.02714], [0.77439, 0.04365], [0.73029, 0.05230], [0.68439, 0.06084], [0.63721, 0.06896], [0.54091, 0.08285], [0.49265, 0.08806], [0.44477, 0.09187], [0.35154, 0.09504], [0.30694, 0.09439], [0.26416, 0.09231], [0.18569, 0.08418], [0.15073, 0.07822], [0.11898, 0.07113], [0.09072, 0.06303], [0.04530, 0.04443], [0.02840, 0.03437], [0.01546, 0.02416], [0.00130, 0.00509], [0.00000, 0.00000], [0.00030, -0.00210], [0.01603, -0.01117], [0.03260, -0.01434], [0.05451, -0.01664], [0.08156, -0.01807], [0.15011, -0.01857], [0.19095, -0.01784], [0.23562, -0.01661], [0.33437, -0.01323], [0.38726, -0.01133], [0.44162, -0.00942], [0.55203, -0.00585], [0.60671, -0.00428], [0.66013, -0.00291], [0.71162, -0.00175], [0.80627, 0.00001], [0.84833, 0.00067], [0.88622, 0.00114], [0.94757, 0.00137], [0.97008, 0.00110], [0.98655, 0.00065], [1.00000, 0.00000]]);

translate([0.9159, 0, 0.0000])
    rotate([0, -0.1458, 0])
        color([0.75, 0.78, 0.80])
            naca_tail(1.3000, 0.2464, [[1.00000, 0.00105], [0.99602, 0.00151], [0.98413, 0.00289], [0.96156, 0.00544], [0.93367, 0.00850], [0.89406, 0.01268], [0.85216, 0.01689], [0.79834, 0.02201], [0.74543, 0.02673], [0.68127, 0.03203], [0.62113, 0.03655], [0.55122, 0.04120], [0.48816, 0.04473], [0.41750, 0.04778], [0.35604, 0.04946], [0.28968, 0.04999], [0.23422, 0.04912], [0.18299, 0.04690], [0.13144, 0.04281], [0.09181, 0.03782], [0.05504, 0.03085], [0.02985, 0.02362], [0.01049, 0.01453], [0.00156, 0.00576], [0.00100, -0.00462], [0.00895, -0.01346], [0.02723, -0.02265], [0.05149, -0.02999], [0.08730, -0.03711], [0.12615, -0.04225], [0.17693, -0.04653], [0.22757, -0.04891], [0.28255, -0.04996], [0.34850, -0.04960], [0.40972, -0.04804], [0.48027, -0.04512], [0.54336, -0.04167], [0.61346, -0.03709], [0.67389, -0.03261], [0.73852, -0.02732], [0.79197, -0.02260], [0.84651, -0.01745], [0.88915, -0.01318], [0.92969, -0.00893], [0.95847, -0.00578], [0.98210, -0.00312], [0.99496, -0.00164], [1.00000, -0.00105]]);

for (s = [-1, 1]) {
    translate([1.2013, s*0.6500, 0])
        color([0.75, 0.78, 0.80])
            vstab_fin([[1.00000, 0.00105], [0.99602, 0.00151], [0.98413, 0.00289], [0.96156, 0.00544], [0.93367, 0.00850], [0.89406, 0.01268], [0.85216, 0.01689], [0.79834, 0.02201], [0.74543, 0.02673], [0.68127, 0.03203], [0.62113, 0.03655], [0.55122, 0.04120], [0.48816, 0.04473], [0.41750, 0.04778], [0.35604, 0.04946], [0.28968, 0.04999], [0.23422, 0.04912], [0.18299, 0.04690], [0.13144, 0.04281], [0.09181, 0.03782], [0.05504, 0.03085], [0.02985, 0.02362], [0.01049, 0.01453], [0.00156, 0.00576], [0.00100, -0.00462], [0.00895, -0.01346], [0.02723, -0.02265], [0.05149, -0.02999], [0.08730, -0.03711], [0.12615, -0.04225], [0.17693, -0.04653], [0.22757, -0.04891], [0.28255, -0.04996], [0.34850, -0.04960], [0.40972, -0.04804], [0.48027, -0.04512], [0.54336, -0.04167], [0.61346, -0.03709], [0.67389, -0.03261], [0.73852, -0.02732], [0.79197, -0.02260], [0.84651, -0.01745], [0.88915, -0.01318], [0.92969, -0.00893], [0.95847, -0.00578], [0.98210, -0.00312], [0.99496, -0.00164], [1.00000, -0.00105]]);
    color([0.15, 0.15, 0.16])
        translate([0.0775, s*0.6500, 0])
            rotate([0, 90, 0])
                cylinder(h=1.4287, r=0.0127);
    color([0.22, 0.24, 0.26]) nacelle(s*0.6500);
    color([0.25, 0.25, 0.28, 0.35])
        translate([-0.7000, s*0.6500, 0])
            rotate([0, 90, 0])
                cylinder(h=0.004, r=0.2032);
}

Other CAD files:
conventional/outputs/aircraft.scad
split_empennage/outputs/aircraft.scad
outputs/snapshots/vstab_arm_156/aircraft.scad
outputs/aircraft.stl
split_empennage/outputs/aircraft.stl

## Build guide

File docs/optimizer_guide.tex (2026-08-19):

\documentclass[11pt,letterpaper]{article}

\usepackage[margin=1in]{geometry}
\usepackage{amsmath,amssymb,amsfonts}
\usepackage{booktabs}
\usepackage{longtable}
\usepackage{array}
\usepackage{tabularx}
\usepackage{enumitem}
\usepackage{hyperref}
\usepackage{xcolor}
\usepackage{setspace}
\usepackage{fancyhdr}
\usepackage{caption}

\hypersetup{
  colorlinks=true,
  linkcolor=blue!50!black,
  urlcolor=blue!50!black,
  citecolor=blue!50!black
}

\setstretch{1.12}
\setlist[itemize]{leftmargin=1.4em,itemsep=0.25em}
\setlist[enumerate]{leftmargin=1.6em,itemsep=0.25em}
\setlength{\parskip}{0.35em}
\setlength{\parindent}{0pt}

\pagestyle{fancy}
\fancyhf{}
\lhead{Solar UAV optimizer}
\rhead{How the model actually works}
\cfoot{\thepage}

\newcommand{\flag}{\textcolor{red!60!black}{\textbf{FLAGGED}}}
\newcommand{\code}[1]{\texttt{#1}}

\newenvironment{intuition}{\begin{quote}\small}{\end{quote}}
\newenvironment{examplebox}{\begin{quote}\small}{\end{quote}}
\newenvironment{warningbox}{\begin{quote}\small}{\end{quote}}

\title{\textbf{How the Solar UAV Optimizer Works}\\[0.4em]
\large Assumptions, constraints, physics, and what the numbers are trying to tell us}
\author{Design toolchain notes for new members\\
\texttt{solar-uav-design} repository}
\date{17 August 2026}

\begin{document}
\maketitle
\tableofcontents
\newpage

% =====================================================================
\section{Start here: the one-page mental model}
% =====================================================================

This repository is not a CAD package and it is not a gradient-based ``optimal control'' solver.
It is a \textbf{physics model plus a discrete search}. For each candidate airplane it answers one question:

\begin{quote}
\textit{If this airframe flies a clear-sky solstice day at our site, with our packs and our motors, does the repeating day stay above 20\% overnight and not get poorer?}
\end{quote}

If yes, the design \emph{closes}. If not, the model reports how far it missed, in watt-hours. Nothing on the locked grid currently closes.

The night, not the day, is the problem. On a June solstice the array makes on the order of 200\,W at noon. Cruise only needs about 75\,W of bus power. The airplane still fails because for about \textbf{14 hours} the array cannot cover cruise, and two packs only store 773\,Wh of usable energy.

\begin{intuition}
\textbf{Intuition.} Think of the battery as a water tank, the motors as a tap, and the solar array as a daytime hose. Closing is not ``does the hose fill the tank to 100\%?'' Closing is ``can the tank last until the hose starts working again, and is Tuesday's tank at least as full as Monday's?'' Extra noon solar that you cannot store does not help the night. Launching full is a one-night gift; the scored day is the next one.
\end{intuition}

Three numbers dominate almost every trade:

\begin{enumerate}
  \item \textbf{Night bus power} --- electrical watts the two motors plus avionics draw in level night loiter.
  \item \textbf{Battery-true night length} --- hours when array power is less than that night load (not sunset-to-sunrise).
  \item \textbf{Usable pack energy} --- $2 \times 483\,\mathrm{Wh} \times 80\% = 773\,\mathrm{Wh}$.
\end{enumerate}

Aero, mass, props, and motors all matter only insofar as they move those three numbers.

Source of truth for locked constants: \code{solar\_uav/config.py}. Every value marked \flag{} is an assumption awaiting a measurement or a team decision. The physics rule is: when uncertain, take the \textbf{pessimistic} side. A design must not close because the model was kind.

% =====================================================================
\section{The airplane and the mission}
% =====================================================================

\subsection{What we are designing}

Twin-boom, OV-10-style solar UAV:

\begin{itemize}
  \item One three-piece wing (S4310): rectangular inboard bay between the booms, two outboard panels that may taper. Leading edge unswept.
  \item Independent tails: NACA~0010 H-stab spanning the booms \emph{in the wing plane}; two NACA~0010 V-stabs further aft (fin LE behind H-stab TE). Not a $\pi$-tail.
  \item One tractor propeller and one motor on each boom.
  \item SunPower C60 cells on the wing top and on the H-stab (ahead of the elevator).
  \item Two Upgrade Energy GOLD V1 6S packs in parallel, Genasun GVB-8-Li-25.0V MPPTs (buck and boost; one per string).
\end{itemize}

No payload. The mission is an 81-hour endurance record, designed to 89 hours (10\% margin). The optimizer launches the design day from a full pack (ground charge), then scores the \textbf{next} 24 hours: dawn must stay at or above 20\%, and that repeating day must not get poorer (start $\le$ end). A first night that only survives because you took off full is not closed.

\subsection{Locked mission requirements}

\begin{center}
\begin{tabular}{@{}ll@{}}
\toprule
Quantity & Value \\
\midrule
Site latitude & $34.646849^\circ\mathrm{N}$ (El Mirage Race Course) \\
Site longitude & $-117.605977^\circ$ (El Mirage Race Course) \\
Site elevation & $2837\,\mathrm{ft} = 864.7\,\mathrm{m}$ MSL (USGS lake bed) \\
Cruise AGL & $400\,\mathrm{ft}$ (density at field + AGL; no ground-effect credit) \\
Timezone & America/Los\_Angeles \\
Design day & 21 June 2027 (solstice, longest day) \\
Mission window & 1 May -- 31 July 2027 \\
MTOW & $\le 12\,\mathrm{kg}$ \\
Span & $\le 6\,\mathrm{m}$ \\
Packs & at most three (integer; 2 or 3 searched) \\
Avionics & $5\,\mathrm{W}$ continuous, day and night (measured) \\
Climb & $\ge 1.5\,\mathrm{m/s}$ \flag{} \\
Min airspeed & $\max(1.2\,V_\mathrm{stall},\; 15\,\mathrm{kt})$ \\
SOC window & 20\%--100\% (80\% of nameplate is usable) \\
\bottomrule
\end{tabular}
\end{center}

Temperatures are a \textbf{hot design-day}: ambient $24^\circ\mathrm{C}$ dawn to $40^\circ\mathrm{C}$ afternoon \flag{}. A real El Mirage June dawn is often cooler and denser. Keeping $24^\circ\mathrm{C}$ dawn is conservative for night aero. Afternoon $40^\circ\mathrm{C}$ is not a desert extreme --- revisit if cells run hotter than the 75\,$^\circ\mathrm{C}$ noon calibration.

% =====================================================================
\section{The conservative-physics rule}
% =====================================================================

If a number is not measured and not in a datasheet range, the model implements the side that makes closure \emph{harder}.

\begin{itemize}
  \item \textbf{Prop maps.} If the (speed, RPM) point is on the manufacturer table, use that $T$ and $P$, density-scaled. Similarity $C_T(J)$ is a check, or a fallback only while the blade is still below windmill $J$. Never invent a slower RPM at fixed speed once a tabulated block already covers that speed.
  \item \textbf{ESC / motor.} Do not treat 95\% ESC efficiency as valid below $\sim$50\% duty. Low-RPM cruise is not a free no-load-current win.
  \item \textbf{Aero.} Do not take unmodeled credits (T-tail height reducing downwash, flight cooling, swirl recovery) unless they \emph{hurt} the metric you care about. Handbook downwash $2C_L/(\pi\,\mathrm{AR})$ is already coarse --- do not ``improve'' it in the direction that lightens tail download.
  \item \textbf{Mass / solar / battery.} Heavier structure, less array, stricter charge limits --- not the reverse.
\end{itemize}

\begin{warningbox}
\textbf{Why this exists.} An earlier interpolator $n^2$-scaled a $22\times12$E propeller down to $\sim$1190\,RPM at night cruise, inventing $J \approx 1.14$ past the map's zero-thrust $J \approx 0.67$. Night bus looked like $\sim$62\,W and the airplane ``closed.'' The honest operating point on the table is $\sim$2070\,RPM and $\sim$133--138\,W. Prefer an honest fail over an optimistic close.
\end{warningbox}

% =====================================================================
\section{What kind of optimizer this is}
% =====================================================================

File: \code{solar\_uav/optimize.py}.

It is a \textbf{mixed continuous / discrete search}. Aero geometry (span, chord, H-stab arm, V-stab arm, boom spacing, taper, washout, elevator fraction) is continuous and is driven by differential evolution (\code{search\_continuous()}). Integer and catalog quantities stay discrete: cell count from packing, pack count (2 or 3, cap 3), motor (A40-12L direct), ESC (fixed mass), and the inner-loop propeller pick.

A legacy exhaustive grid (\code{search()}) remains for neighborhood dumps. Do not use it as the production path --- it is the slow nested loop that used to take tens of minutes.

The inner loop (\code{\_best\_prop}) is not part of the outer product. For each airframe it:

\begin{enumerate}
  \item Tries every shortlisted propeller.
  \item Keeps only those that can make night thrust on 6S.
  \item Ranks them by night bus power (lowest first).
  \item Accepts the first that also meets the $1.5\,\mathrm{m/s}$ climb rule.
\end{enumerate}

So ``the optimizer evaluated 51 props'' does \emph{not} mean $51\times$ the airframe grid. Each airplane picks one fan.

Ranking of results: closed designs first, then highest \code{margin\_wh}. If none closed, the top row is the nearest miss.

Default motor is the A40-12L kv410 direct-drive. Geared A40-10L / 10S stay in the catalog for compare scripts only and are not searched.

% =====================================================================
\section{Optimization objective}
% =====================================================================

\textbf{Maximize 24-hour energy margin} (watt-hours above the 20\% SOC floor on the repeating day), subject to periodicity, climb, MTOW, span, solar layout, and trim/pitch.

After the two-day march (day 1 from SOC $=1$, day 2 from wherever day 1 ended),

\begin{align}
  E_\mathrm{reserve}
    &= (\mathrm{SOC}_\mathrm{min} - 0.20)\,E_\mathrm{pack,total}, \\
  E_\mathrm{cycle}
    &= (\mathrm{SOC}_\mathrm{end} - \mathrm{SOC}_\mathrm{start})\,E_\mathrm{pack,total}, \\
  \mathrm{margin}
    &= E_\mathrm{reserve}.
\end{align}

$\mathrm{SOC}_\mathrm{min}$, $\mathrm{SOC}_\mathrm{start}$, and $\mathrm{SOC}_\mathrm{end}$ are all on \textbf{day 2}. $E_\mathrm{cycle}$ is a diagnostic: it must be $\ge -0.5\,\mathrm{Wh}$ to close, but it is not stacked into the score. If the pack could not supply the requested power at any step, margin is also capped at $-\,E_\mathrm{unmet}$.

\begin{intuition}
\textbf{Intuition.} $\mathrm{SOC}_\mathrm{min}$ is ``did we scrape the floor at dawn on the repeating day?'' $\mathrm{SOC}_\mathrm{end} \ge \mathrm{SOC}_\mathrm{start}$ is ``is Tuesday at least as rich as Monday?'' A design that holds 20\% on the first night from a full launch and then ratchets is not a winner. We do not require the pack to hit 98\%.
\end{intuition}

A design is \textbf{closed} only if all of these hold:

\begin{itemize}
  \item $\mathrm{SOC}_\mathrm{min} \ge 0.20$ (day 2)
  \item unmet energy $< 0.5\,\mathrm{Wh}$ (day 2)
  \item climb $\ge 1.5\,\mathrm{m/s}$
  \item $E_\mathrm{cycle} \ge -0.5\,\mathrm{Wh}$ (day 2 does not get poorer)
\end{itemize}

Margin on the current nearest-miss, scored on the repeating day, is worse than the old first-night figure: $\mathrm{SOC}_\mathrm{min} = 0.007$, a $-28\,\mathrm{Wh}$ cycle, and $80\,\mathrm{Wh}$ unmet. The 20\% floor is still what fails. Extra noon solar mostly spills; you need energy \emph{during the night}. The old 98\% refill gate is gone; this row also ratchets.

% =====================================================================
\section{Constraints}
% =====================================================================

\subsection{Hard constraints (candidate is discarded before the mission march)}

Implemented in \code{\_hard\_constraints} and the packing checks:

\begin{center}
\begin{tabular}{@{}lp{0.62\textwidth}@{}}
\toprule
Name & Rule \\
\midrule
Span & $b \le 6\,\mathrm{m}$ \\
Mass & $m \le 12\,\mathrm{kg}$ (re-checked after the prop is chosen) \\
Solar layout & cells fit the bays; each series string stays within the GVB-8 Voc/power cap \\
Stall & $1.2\,V_\mathrm{stall} \le 25\,\mathrm{m/s}$ (sanity cap) \\
Stability & static margin $\ge 8\%\,\mathrm{MAC}$, elevator trim, pitch acceleration $\ge 0.30\,\mathrm{rad/s^2}$, roll rate $\ge 35^\circ/\mathrm{s}$, differential-thrust yaw vs $5^\circ$ sideslip and yaw rate $\ge 5^\circ/\mathrm{s}$ (no rudder). $C_{n_\beta}$ / $|C_{n_r}|$ floors off; derivatives still computed. \\
Boom & carbon tube length $> 0.4\,\mathrm{m}$ \\
V-stab / H-stab & V-stab leading edge at or behind H-stab trailing edge (also enforced by flooring $\ell_v$) \\
Propulsion & some shortlisted prop can make night thrust on 6S \emph{and} climb \\
\bottomrule
\end{tabular}
\end{center}

\subsection{Energy constraints (scored, not discarded)}

Candidates that fail the SOC floor or the day-2 cycle are still written to the CSV so we can see nearest misses. Climb failure also appears in the reason string.

\subsection{Electrical / packing constraints baked into geometry}

\begin{itemize}
  \item One series string per bay on the locked search (inboard, left outboard, right outboard, H-stab). Strings do not cross joints.
  \item The GVB-8 bucks and boosts, so string Voc may sit above the 6S bus. Remaining caps: cold-cell Voc $\le 50\,\mathrm{V}$ (recommended STC Voc; 60\,V is the absolute input) and STC string power $\le 210\,\mathrm{W}$. That is \textbf{61 cells}/string on bin I (the 210\,W rating binds before 50\,V).
  \item Genasun input $\le 8\,\mathrm{A}$; C60 $I_\mathrm{mp} \approx 5.9\,\mathrm{A}$, so one series string per MPPT is fine.
  \item Layout pitch $130\,\mathrm{mm}$ (cell is $125\,\mathrm{mm}$ plus gap). A $300\,\mathrm{mm}$ chord still fits two rows.
  \item After packing, every claimed cell is placed as a $125\,\mathrm{mm}$ square and rejected if it overlaps another cell or hangs off the planform (taper, aileron keep-out, elevator keep-out).
  \item H-stab cells only on the fixed portion; elevator chord is keep-out (split elevons).
  \item Tapered wing: no cells on the aileron chord. Rectangular wing: cells may cover ailerons.
\end{itemize}

% =====================================================================
\section{Decision variables and search grids}
% =====================================================================

Aero variables are continuous. Integer / catalog items stay discrete. Every continuous quantity has a \texttt{(low, high, start)} triple in \code{config.CONTINUOUS}. User-locked starts (chord $310\,\mathrm{mm}$, tail arm $0.90\,\mathrm{m}$, airspeed $12\,\mathrm{m/s}$) are not overwritten.

\begin{center}
\begin{tabular}{@{}lll@{}}
\toprule
Variable & Bounds / start & Notes \\
\midrule
\multicolumn{3}{l}{\emph{In the DE vector}} \\
Span $b$ & $4.50$--$6.00\,\mathrm{m}$, start $6.00$ & hard cap $6\,\mathrm{m}$ \\
Root chord $c_r$ & $0.300$--$0.52\,\mathrm{m}$, start $310\,\mathrm{mm}$ & two C60 rows; high = four pitches \\
H-stab arm $\ell_t$ & $0.80$--$2.00\,\mathrm{m}$, start $0.90$ & wing AC to H-stab AC \\
V-stab arm $\ell_v$ & $0.80$--$3.00\,\mathrm{m}$, start $1.20$ & floored so V-stab LE $\ge$ H-stab TE \\
Elevator fraction & $0.22$--$0.40$, start $0.34$ & split elevons; keep-out for H-stab cells \\
Taper $\lambda = c_\mathrm{tip}/c_r$ & $0.40$--$1.0$, start $0.60$ & $1.0$ is rectangular; $0.40$ still packs a tip cell \\
Taper start & $0$--$1$ of outboard, start $0.50$ & $0$ = taper from the boom \\
Boom spacing & $1.04$--$2.21\,\mathrm{m}$, start $1.30$ & $8$--$17$ cell pitches; H-stab span = boom spacing \\
Washout tip & $0^\circ$--$5^\circ$, start $0^\circ$ & $5^\circ$ is a lot at this AR \\
Washout start & $0$--$1$ of outboard, start $0$ & unused at $0^\circ$ washout \\
\midrule
\multicolumn{3}{l}{\emph{Continuous, nested (not DE)}} \\
Loiter airspeed & $8$--$18\,\mathrm{m/s}$, start $12$, $0.01\,\mathrm{m/s}$ step & still floored by $1.3\,V_s$ / $15\,\mathrm{kt}$ \\
\midrule
\multicolumn{3}{l}{\emph{Continuous, held at start}} \\
H-stab AR & $3.5$--$6.0$, start $4.5$ & not in the DE vector \\
V-stab AR & $1.5$--$3.5$, start $1.5$ & per fin; held at start \\
Aileron chord frac & $0.20$--$0.30$, start $0.25$ & locked for S\&C sizing \\
\midrule
\multicolumn{3}{l}{\emph{Discrete / catalog}} \\
Packs & $\{2,3\}$ & cap 3; one DE per pack count \\
Motor & A40-12L kv410 direct & not searched \\
ESC & fixed $0.060\,\mathrm{kg}$ lump & not searched \\
$N_\mathrm{cells}$ & from packing & integer, one MPPT-legal string per bay \\
Prop & inner loop, see \S\ref{sec:props} & discrete catalog \\
\bottomrule
\end{tabular}
\end{center}

The production search is \code{optimize.search\_continuous()} (differential evolution, start at the DE table above). A neighborhood grid dump is optional via the legacy \code{search()} path.

% =====================================================================
\section{How one candidate is scored}
% =====================================================================

Walk this loop in your head for every row of the CSV.

\begin{enumerate}
  \item Build geometry: planform, boom spacing, H-stab in the wing plane sized to $V_H = 0.50$ (chord also floored by one cell row), V-stabs to $V_V = 0.030$ at their own arm $\ell_v$ (no 1.30\,m area floor), carbon tube from wing $c/4$ to V-stab trailing edge, fuselage pods from wing TE to the prop disk.
  \item Pack cells: one MPPT-legal series string per bay. Reject if cells overlap or hang off the planform.
  \item Sum mass. Drop if $>12\,\mathrm{kg}$.
  \item Check stall, static margin, elevator, pitch, roll rate, weathercock, yaw damping.
  \item For each propeller: night drag at min-power speed $\to$ RPM on the map $\to$ bus watts. Rank by night watts. Keep the cheapest that still climbs at 25.2\,V.
  \item March 24 hours: solar from pvlib, load = night bus or day bus, $P_\mathrm{net} = P_\mathrm{solar} - P_\mathrm{load}$, battery with 6\,A/pack charge cap.
  \item Record $\mathrm{SOC}_\mathrm{min}$, $\mathrm{SOC}_\mathrm{end}$, margin, flags (especially prop table vs.\ similarity).
\end{enumerate}

The rest of this document is the physics inside those steps.

% =====================================================================
\section{Atmosphere and site}
% =====================================================================

Files: \code{solar\_uav/aircraft.py} (density), \code{solar\_uav/environment.py} (sun and temperature).

Site pressure is ISA-style at field elevation plus $400\,\mathrm{ft}$ AGL ($h \approx 987\,\mathrm{m}$ MSL):

\begin{equation}
  p = 101325
  \left(1 - 2.25577\times 10^{-5}\, h\right)^{5.25588}
  \quad [\mathrm{Pa}].
\end{equation}

Density is the ideal-gas law at that pressure:

\begin{equation}
  \rho = \frac{p}{R T}, \qquad R = 287.05\,\mathrm{J/(kg\,K)}.
\end{equation}

Two densities are frozen for the mission (AeroSandbox ISA at field $+$ 400\,ft AGL, with the design-day temperature offset):

\begin{itemize}
  \item Night: $T = 26^\circ\mathrm{C}$ ($T_\mathrm{amb,min}+2$) $\Rightarrow$ $\rho_N = 1.048\,\mathrm{kg/m^3}$.
  \item Day: $T = 36^\circ\mathrm{C}$ ($T_\mathrm{amb,max}-4$) $\Rightarrow$ $\rho_D = 1.014\,\mathrm{kg/m^3}$.
\end{itemize}

Air viscosity is Sutherland's law at the night temperature, $\mu = 1.84\times 10^{-5}\,\mathrm{Pa\,s}$. Reynolds number of a length $\ell$ is

\begin{equation}
  \mathrm{Re}_\ell = \frac{\rho V \ell}{\mu}.
\end{equation}

\begin{intuition}
\textbf{Intuition.} Hot air is thinner, and El Mirage at $\sim$987\,m MSL is already thinner than sea level. A thinner night means the wing needs a higher $C_L$ (or more speed) to hold the same weight, so induced drag rises. Using a hot dawn is deliberately unkind to night watts. Ground effect is not credited: density is at field $+$ 400\,ft AGL, not a cushion of extra lift near the lake bed.
\end{intuition}

% =====================================================================
\section{Geometry}
% =====================================================================

\subsection{Wing planform}

The wing is three pieces. Inboard, between the booms, the chord is $c_r$. Outboard of each boom the chord stays $c_r$ until a taper-start station, then linearly tapers to $c_\mathrm{tip} = \lambda c_r$. Leading edge unswept, so taper is trailing-edge cut.

Let $y_b$ be half the boom spacing and $L_\mathrm{out} = b/2 - y_b$ the outboard panel length. With taper-start fraction $f$ (0 = start at the boom),

\begin{align}
  L_\mathrm{rect} &= f\, L_\mathrm{out}, \\
  L_\mathrm{tap}  &= (1-f)\, L_\mathrm{out}, \\
  S &= 2 y_b c_r + 2 L_\mathrm{rect} c_r + L_\mathrm{tap}(c_r + c_\mathrm{tip}).
\end{align}

Mean aerodynamic chord for an unswept piecewise-linear planform:

\begin{equation}
  \bar{c} = \frac{2}{S}\int_{-b/2}^{b/2} c(y)^2\,\mathrm{d}y.
\end{equation}

Aspect ratio is the usual $ \mathrm{AR} = b^2 / S $.

Boom spacing and area depend on each other (H-stab span = boom spacing, and $V_H$ uses $S$ and $\bar{c}$), so the code iterates that loop 16 times.

\subsection{Horizontal tail}

Target tail volume

\begin{equation}
  V_H = \frac{S_H \ell_t}{S \bar{c}} = 0.50 \quad \text{\flag{}}.
\end{equation}

When boom spacing is forced (e.g.\ $1.30\,\mathrm{m}$), H-stab span equals that spacing and chord is

\begin{equation}
  c_H = \max\left(\frac{V_H S \bar{c}}{\ell_t\, b_\mathrm{boom}},\;
  c_{H,\min}\right),
\end{equation}

where $c_{H,\min}$ is the chord that still fits one $130\,\mathrm{mm}$ cell row after the elevator keep-out. That is why a short tail arm does not shrink the H-stab to nothing: solar packing floors the chord.

\subsection{Vertical tails}

The V-stab aerodynamic centre sits on its own arm $\ell_v$, independent of the H-stab arm $\ell_t$. Total area (both fins)

\begin{equation}
  V_V = \frac{S_V \ell_v}{S b} = 0.030 \quad \text{(user; both fins together)}.
\end{equation}

There is \textbf{no} fin-area floor at a 1.30\,m arm: stretching $\ell_v$ shrinks $S_V$ at fixed $V_V$. Each fin has area $S_V/2$ and $\mathrm{AR}_V = 1.5$ (held at the start of \code{CONTINUOUS}). No rudder; yaw control is differential thrust. No $\pi$-tail endplate credit on $C_{n_\beta}$.

The V-stab leading edge is required to sit at or behind the H-stab trailing edge:

\begin{equation}
  \ell_v \ge \ell_t + 0.75\, c_H + 0.25\, c_V(\ell_v).
\end{equation}

$c_V$ shrinks as $\ell_v$ grows, so the code iterates to the fixed point and floors any requested $\ell_v$ that would overlap the H-stab in $x$.

\subsection{Boom length}

The carbon tube runs from the wing quarter-chord (at the boom) to the V-stab trailing edge. The fuselage pod covers prop disk $\to$ wing trailing edge and is \emph{not} part of $L_\mathrm{boom}$.

\begin{equation}
  L_\mathrm{boom} = x_{\mathrm{V,TE}} - \tfrac14 c_r,
\end{equation}

where $x_{\mathrm{V,TE}} = \tfrac14 \bar{c} + \ell_v + \tfrac34 c_V$. The H-stab camber is in the \textbf{wing plane} ($z_H = 0$); the fins stand up from the boom further aft. Fuselage length and CAD-scaled wetted area (one pod):

\begin{align}
  L_\mathrm{fuse} &= 0.70\,\mathrm{m} + c_r, \\
  S_{\mathrm{wet,fuse}} &= 173128.421\,\mathrm{mm}^2 \times \frac{L_\mathrm{fuse}}{980\,\mathrm{mm}}.
\end{align}

The $980\,\mathrm{mm} / 173128.421\,\mathrm{mm}^2$ point is from CAD. Linear scale assumes constant section (motor/spinner girth does not grow with chord).

% =====================================================================
\section{Mass}
% =====================================================================

Wetted-area factor $k_w = 2.05$ (both sides plus a little thickness). Wing structure uses $0.84\times 0.8 = 0.672\,\mathrm{kg/m^2}$ of wetted area (user, 17 August 2026: 0.8$\times$ the previous main-wing model only), \emph{including} encapsulation, \emph{excluding} cells. Tails stay at $0.44\,\mathrm{kg/m^2}$ wetted.

\begin{align}
  m_\mathrm{wing}  &= 2.05\, S \times 0.672, \\
  m_{H}            &= 2.05\, S_H \times 0.44, \\
  m_{V}            &= 2.05\, S_V \times 0.44, \\
  m_\mathrm{booms} &= 2 \times L_\mathrm{boom} \times 0.174\,\mathrm{kg/m}, \\
  m_\mathrm{cells} &= N_\mathrm{cells} (0.0065 + 0.0015)\,\mathrm{kg}, \\
  m_\mathrm{MPPT}  &= N_\mathrm{strings} \times 0.108\,\mathrm{kg}, \\
  m_\mathrm{batt}  &= 2 \times 1.278\,\mathrm{kg}.
\end{align}

Boom linear density $0.174\,\mathrm{kg/m}$ is the 1.0\,in OD carbon tube (was $0.290\,\mathrm{kg/m}$ at $\varnothing 38.1\,\mathrm{mm}$). Parasite drag uses the 25.4\,mm OD.

Fixed masses (prototype table): avionics 0.30, power boards 0.10, servos 0.08, ESCs 0.06, wiring 0.096, fuselage pods 0.20, superstructures 0.20, boom/V-stab interfaces 0.10, boom/H-stab fittings 0.06 (same lump as the old $\pi$-tip joint). Total fixed $= 1.196\,\mathrm{kg}$.

Motors and props are catalog masses (two of each).

\begin{examplebox}
\textbf{Worked example --- current nearest-miss} ($b=5.91$, $c_r=0.314$, $\lambda=0.60$, $\ell_t=1.28$, $\ell_v=1.70$, 76 cells).

\begin{center}
\begin{tabular}{@{}lr@{}}
\toprule
Item & Mass [kg] \\
\midrule
Wing structure & 2.25 \\
H-stab & 0.22 \\
V-stabs & 0.15 \\
Booms ($2\times 1.87\,\mathrm{m}\times 0.174$) & 0.65 \\
Cells + interconnect & 0.61 \\
Four MPPTs & 0.43 \\
Two packs & 2.56 \\
Two A40-12L & 0.55 \\
Two APC $16\times12$E & 0.12 \\
Fixed & 1.20 \\
\midrule
\textbf{Total} & \textbf{8.75} \\
\bottomrule
\end{tabular}
\end{center}

The 0.8$\times$ wing areal cut $\sim$0.6\,kg off the previous 0.84\,kg/m$^2$ wing. The 1\,in tube is both lighter per metre and thinner in parasite drag than the 1.5\,in / 0.290\,kg/m boom. The V-stabs are smaller than a co-located $\pi$-tail at $\ell_t$ because $\ell_v$ is longer at fixed $V_V$. Batteries are still the heaviest single lump.
\end{examplebox}

\begin{intuition}
\textbf{Intuition.} You do not ``buy'' span for free. A 6\,m wing at 0.672\,kg/m$^2$ wetted is already $\sim$2.3\,kg before cells. Lengthening $\ell_v$ (not just $\ell_t$) adds carbon on \emph{both} booms, because the tube still runs to the V-stab trailing edge. That extra mass flies all night.
\end{intuition}

% =====================================================================
\section{Aerodynamics}
% =====================================================================

File: \code{solar\_uav/aircraft.py}. Airfoil polars: NeuralFoil \code{xlarge} via AeroSandbox, cached in \code{data/polars/}. Wing section is S4310; tails are NACA~0010. Polar grid: $\mathrm{Re} \in \{50,100,150,200,300\}\times 10^3$, $\alpha \in [-6^\circ, 16^\circ]$ at $0.25^\circ$.

NeuralFoil polars are not monotonic in $C_L$ at negative $\alpha$. The code takes the \textbf{increasing-$C_L$ pre-stall branch} (from $C_{L,\min}$ to $C_{L,\max}$), then interpolates $c_d$, $\alpha$, and $c_m$ versus $C_L$ and $\log\mathrm{Re}$.

\subsection{Level-flight lift}

Dynamic pressure and net lift coefficient (weight on the wing reference area):

\begin{equation}
  q = \tfrac12 \rho V^2, \qquad
  C_{L,\mathrm{net}} = \frac{mg}{q S}.
\end{equation}

The H-stab carries a (usually negative) load, so the wing must make a little more than $C_{L,\mathrm{net}}$:

\begin{equation}
  C_{L,w}\, S + C_{L,H}\, S_H = mg
  \quad \Rightarrow \quad
  C_{L,w} = C_{L,\mathrm{net}} - \frac{S_H}{S} C_{L,H}.
\end{equation}

$C_{L,H}$ is not a guess. It comes from the trim iteration below.

\begin{intuition}
\textbf{Intuition.} $C_{L,\mathrm{net}}$ is ``how hard is this wing working, as a whole, to hold the airplane up?'' If the tail is pushing down, the wing has to make \emph{more} lift than the weight, and induced drag is paid on that higher wing $C_L$. That is why a badly trimmed tail is not free.
\end{intuition}

\subsection{Lift-curve slopes (Helmbold)}

Finite-wing lift slope, per radian:

\begin{equation}
  a = \frac{2\pi}{1 + 2/\mathrm{AR}}.
\label{eq:helmbold}
\end{equation}

Used for the wing ($a_w$) and the H-stab ($a_t$ with the H-stab's actual AR). This is the classical correction that a high-AR wing is closer to $2\pi$ and a stubby tail is much less.

Downwash derivative at the tail, handbook:

\begin{equation}
  \frac{\mathrm{d}\varepsilon}{\mathrm{d}\alpha} = \frac{2 a_w}{\pi\,\mathrm{AR}}.
\end{equation}

\subsection{Oswald efficiency (induced-drag factor)}

Rectangular calibration $e_0 = 0.90$ \flag{}. Taper scales that using AeroSandbox's Nita--Scholz estimate:

\begin{equation}
  e = \min\left(0.98,\;
      e_0 \frac{e_\mathrm{Nita}(\lambda_\mathrm{eq},\mathrm{AR})}
               {e_\mathrm{Nita}(1,\mathrm{AR})}\right).
\end{equation}

$\lambda_\mathrm{eq}$ is an equivalent taper from the actual area and tip chord, clipped to $[0.2, 1]$. The 0.98 cap is a hard ceiling: we do not claim a better-than-nearly-elliptical wing.

On the current $\lambda = 0.60$, $\mathrm{AR} = 21.3$ airplane, this \textbf{hits the 0.98 cap}.

\begin{intuition}
\textbf{Intuition.} Induced drag is the price of making lift with a finite wing: the tip vortices tilt the lift vector backward. Elliptical spanload pays the minimum price, $C_{D_i} = C_L^2/(\pi\,\mathrm{AR})$. Oswald $e$ is ``how close are we to that ellipse?'' $e=0.90$ is an honest rectangle. $e=0.98$ is ``this taper already did most of the job.'' That is why adding washout on top of $\lambda=0.4$ does not buy much --- there is almost no induced-drag left to save, and the cap forbids claiming more.
\end{intuition}

\subsection{Induced drag of the wing}

\begin{equation}
  C_{D_i,w} = \frac{C_{L,w}^2}{\pi\,\mathrm{AR}\, e}.
\label{eq:cdi}
\end{equation}

If washout is zero, that is the whole induced model. If washout is nonzero, $e$ is replaced by an effective $e$ from lifting-line (see \S\ref{sec:washout}).

\subsection{Wing profile drag}

At the local $(C_{L,w}, \mathrm{Re}_{\bar{c}})$, read $c_d$ from the S4310 NeuralFoil polar:

\begin{equation}
  C_{D_{p,w}} = c_{d,\mathrm{S4310}}\!\left(C_{L,w},\, \mathrm{Re}_{\bar{c}}\right).
\end{equation}

This is a 2D section drag treated as constant across the span when washout is zero. With washout, a strip integral adds the difference vs.\ the untwisted wing (again \S\ref{sec:washout}).

\subsection{Horizontal-stabilizer drag}

Profile from NACA~0010 at the tail's $C_{L,H}$ and $\mathrm{Re}_{c_H}$. Induced with a conservative tail Oswald $e_H = 0.70$:

\begin{equation}
  C_{D_{p,H}} = c_{d,0010}(C_{L,H}, \mathrm{Re}_{c_H}), \qquad
  C_{D_{i,H}} = \frac{C_{L,H}^2}{\pi\,\mathrm{AR}_H \cdot 0.70}.
\end{equation}

These coefficients are referenced to $S_H$, not $S$.

\subsection{Vertical-stabilizer drag}

Both fins at $C_L = 0$ (no sideslip in the cruise model):

\begin{equation}
  C_{D_{p,V}} = c_{d,0010}(0, \mathrm{Re}_{c_H}),
\end{equation}

referenced to $S_V$ (the H-stab chord Reynolds number is used as a stand-in for the fin). No induced term: they are not lifting in this model.

\subsection{Parasite drag of pods and booms}

Turbulent skin friction (Blasius-like power law, floored at $\mathrm{Re}=10^4$):

\begin{equation}
  C_f = \frac{0.074}{\mathrm{Re}^{0.2}}.
\end{equation}

Two fuselage pods. Wetted area is interpolated from CAD ($173128.421\,\mathrm{mm}^2$ at $L=980\,\mathrm{mm}$), Reynolds number on the actual pod length $L_\mathrm{fuse} = 0.70\,\mathrm{m}+c_r$, form factor 1.25:

\begin{equation}
  f_\mathrm{pods} = 2\, C_f(\mathrm{Re}_{L_\mathrm{fuse}}) \cdot 1.25 \cdot S_{\mathrm{wet,fuse}}(L_\mathrm{fuse}).
\end{equation}

Two circular booms, wetted area $\pi D L$ per tube, $D = 1.0\,\mathrm{in} = 25.4\,\mathrm{mm}$, form/interference 1.10 on the booms, then another 1.10 on the sum:

\begin{align}
  f_\mathrm{booms} &= 2\, C_f(\mathrm{Re}_L) \cdot 1.10 \cdot (\pi D L_\mathrm{boom}), \\
  f_\mathrm{parasite} &= 1.10\,(f_\mathrm{pods} + f_\mathrm{booms}).
\end{align}

$f$ is a drag area: $D = q f$. No laminar-run credit, no T-tail wake shielding.

\subsection{Putting drag together}

\begin{equation}
\begin{aligned}
  D = q \Big[&
      S \bigl(C_{D_{p,w}} + C_{D_{i,w}}\bigr)
    + S_H \bigl(C_{D_{p,H}} + C_{D_{i,H}}\bigr) \\
    &+ S_V C_{D_{p,V}}
    + f_\mathrm{parasite}
  \Bigr] \times k_\mathrm{trim}.
\end{aligned}
\label{eq:drag}
\end{equation}

$k_\mathrm{trim} = 1.00$. There is no lumped ``trim drag fudge.'' Trim is modeled by actually loading the tail.

\subsection{Incidence and trim}
\label{sec:trim}

The wing is jigged so the \textbf{booms fly at $\alpha \approx 0$} at night min-airspeed. That is a structural / packaging choice (the carbon tubes want to be at zero), not an aerodynamic optimum.

NeuralFoil gives the 2D geometric angle $\alpha_{2D}$ that produces the cruise $C_L$ on S4310. The wing also has an induced angle $C_L/(\pi\,\mathrm{AR}\,e)$. Boom angle of attack is

\begin{equation}
  \alpha_\mathrm{boom} = \alpha_{2D} + \frac{C_L}{\pi\,\mathrm{AR}\,e} - i_w.
\end{equation}

Setting $\alpha_\mathrm{boom}=0$ at the design point:

\begin{equation}
  i_w = \alpha_{2D}(C_L) + \frac{C_L}{\pi\,\mathrm{AR}\,e}.
\label{eq:iw}
\end{equation}

On the current airplane, $i_w \approx 3.70^\circ$.

The H-stab is jigged so the \textbf{elevator is $\approx 0$} at that same point. Handbook downwash at the tail:

\begin{equation}
  \varepsilon = \frac{2 C_{L,w}}{\pi\,\mathrm{AR}}
  \qquad \text{(radians; no T-tail height credit)}.
\label{eq:eps}
\end{equation}

Section $c_m$ about $c/4$ from NeuralFoil, tail volume $V_H$, tail lift slope $a_t$:

\begin{equation}
  i_t = \varepsilon + \frac{c_m}{V_H a_t}
  \qquad \text{(angles in consistent units)}.
\label{eq:it}
\end{equation}

On the current airplane, $i_t \approx 0.07^\circ$.

Inside \code{drag\_n}, three iterations:

\begin{enumerate}
  \item From current $C_{L,w}$, get $\alpha_{2D}$ and $\alpha_i = C_{L,w}/(\pi\,\mathrm{AR}\,e)$.
  \item Boom $\alpha_f = \alpha_{2D} + \alpha_i - i_w$.
  \item $C_{L,H} = a_t\,(\alpha_f + i_t - \varepsilon)$.
  \item $C_{L,w} \leftarrow C_{L,\mathrm{net}} - (S_H/S) C_{L,H}$.
\end{enumerate}

\begin{intuition}
\textbf{Intuition for \eqref{eq:eps}.} A lifting wing throws air down. The tail flies in that descending wake, so it sees a more negative angle than the boom. $\varepsilon \approx 2C_L/(\pi\,\mathrm{AR})$ is the standard horseshoe-vortex estimate: more lift or less AR $\Rightarrow$ stronger downwash. A T-tail sits higher, in weaker downwash. The H-stab is in the \textbf{wing plane}, so there is no height credit to take. If VLM at that $z_H=0$ is \emph{stronger} than handbook, production uses VLM (currently $k_\varepsilon \approx 1.21$). We never keep a $k_\varepsilon<1$ ``T-tail'' gift.
\end{intuition}

AeroSandbox is used as a \textbf{conservative envelope}, not as the scoring polar (\code{solar\_uav/asb\_physics.py}):

\begin{itemize}
  \item Atmosphere is the AeroSandbox ISA at field $+$ 400\,ft AGL, with the design-day temperature offset.
  \item Wing-only VLM downwash at the real H-stab height ($z_H=0$): if it is \emph{weaker} than \eqref{eq:eps}, keep the handbook (no T-tail credit). If it is stronger, use VLM. Induced $e$ is $\min(e_\mathrm{handbook}, e_\mathrm{VLM})$.
  \item AeroBuildup $C_{l_p}$, $C_{n_\beta}$, $C_{n_r}$: keep the number that makes roll rate, weathercock, or yaw damping \emph{harder}.
  \item Pitch inertia is $\max($lumped, CAD-located \code{MassProperties} $I_{yy})$. Area-painted thin-shell inertia is printed as a FLAG and not used.
  \item XFoil vs NeuralFoil at cruise $C_L$: inflate section $c_d$ if XFoil is draggier; never deflate. If the XFoil binary is missing, FLAG and keep NeuralFoil.
\end{itemize}

Run \code{scripts/run\_asb\_audit.py} to print the envelope on the reference airplane.

\subsection{Static margin}

CG is locked at the wing quarter-chord \flag{}. Neutral-point shift is then entirely the tail:

\begin{equation}
  \mathrm{SM}
    = V_H \frac{a_t}{a_w}
      \left(1 - \frac{\mathrm{d}\varepsilon}{\mathrm{d}\alpha}\right).
\end{equation}

Target was 12\% MAC; minimum accepted is 8\%. The current airplane sits at \textbf{43\% MAC} --- very stable. $V_H$ comes out $0.69$ rather than the $0.50$ volume target because the H-stab chord is floored by one $130\,\mathrm{mm}$ cell row after the elevator keep-out. That extra tail is packing, not an SM request.

Elevator effectiveness is the empirical stand-in $\tau = \sqrt{c_e/c}$ \flag{}. Elevator must trim a $\Delta C_L = 1$ at $\le 15^\circ$. Pitch acceleration about the CG must reach $0.30\,\mathrm{rad/s^2}$ ($\sim 20^\circ$ in 1.5\,s from rest) at min airspeed.

\subsection{Stall and the speeds we actually fly}

2D $C_{L,\max}$ is the peak of the NeuralFoil pre-stall branch. 3D knockdown:

\begin{equation}
  C_{L,\max,3\mathrm{D}} = 0.90\, C_{L,\max,2\mathrm{D}}.
\end{equation}

For S4310, $C_{L,\max,2\mathrm{D}} \approx 1.44$, so $C_{L,\max,3\mathrm{D}} \approx 1.30$. Stall speed:

\begin{equation}
  V_s = \sqrt{\frac{2mg}{\rho S C_{L,\max,3\mathrm{D}}}}.
\end{equation}

Operational floor (flown loiter speed):

\begin{equation}
  V_{\min} = \max\bigl(1.3\, V_s,\; 7.7\,\mathrm{m/s}\bigr).
\end{equation}

$1.2\,V_s$ remains a never-below stall margin. The 89-hour flight is a banked loiter, so the energy march pays $1.3\,V_s$. The $7.7\,\mathrm{m/s}$ is 15\,kt of required crosswind capability. On the current airplane $1.3 V_s = 11.42\,\mathrm{m/s}$ and \textbf{binds}: unconstrained aero min-power is $\sim$9.2\,m/s ($DV \approx 29\,\mathrm{W}$ vs.\ $36\,\mathrm{W}$ at the floor). That extra 2.2\,m/s is about $+10\,\mathrm{W}$ of night bus.

Cruise is \textbf{not} $V_{\min}$ blindly. It is the speed $\ge V_{\min}$ that minimises shaft power $P_\mathrm{aero} = D V$. The 1-D search is bounded to $8$--$18\,\mathrm{m/s}$, starts at $12\,\mathrm{m/s}$, and refines to $0.01\,\mathrm{m/s}$ (Brent), still floored by the loiter margin. On the current airplane the floor \textbf{is} the min-power point: unconstrained aero min-power is $\sim$9.2\,m/s, but $1.3 V_s = 11.42\,\mathrm{m/s}$ binds.

\begin{intuition}
\textbf{Why min power, not max $L/D$?} Endurance on a battery cares about \emph{watts}, not distance. Max $L/D$ minimises drag (energy per metre). Min $D V$ minimises energy per second. For a solar loiterer the clock is the enemy, so we fly min power. The extra $1.3$ factor (vs.\ $1.2$) is so a $20^\circ$ bank does not eat the stall margin --- $\sqrt{1/\cos 20^\circ}\approx 1.03$, so $1.3$ already covers turn-stall.
\end{intuition}

Climb is the ideal excess-power expression at day min-power speed, using max thrust available on 25.2\,V:

\begin{equation}
  \dot{h} = V \frac{T - D}{mg}.
\end{equation}

No acceleration, no prop-in-climb polar change, no takeoff ground roll. On the 12L + APC $16\times12$E this is $\sim 15\,\mathrm{m/s}$ versus a $1.5\,\mathrm{m/s}$ requirement. Climb is not the constraint. It only vetoes fans that are efficient at cruise but cannot pull.

\subsection{Ailerons, elevons, and fins}
\label{sec:control}

The performance polar does not fly the airplane. Roll, weathercock, and yaw damping are hard constraints so a later sim cannot inherit a 5$^\circ$/s placeholder.

\textbf{Ailerons} are 25\% local chord. On a taper they start where the second cell row drops (or further inboard if 35$^\circ$/s is not met) and carry no cells on the moving surface. On a rectangle, cells may cover the aileron. \textbf{Elevons} are the existing elevator, split left/right, used differentially for extra roll. There is \textbf{no rudder}; yaw is differential thrust.

Steady roll helix (full $20^\circ$ aileron + $20^\circ$ elevon):

\begin{equation}
  \frac{p b}{2V} = -\frac{C_{l_{\delta a}}\delta_a + C_{l_{\delta e}}\delta_e}{C_{l_p}},
  \qquad
  C_{l_{\delta a}} = \frac{2 a_w \tau}{S b}\int_{y_1}^{y_2} c(y)\, y\,\mathrm{d}y.
\end{equation}

$C_{l_p}$ is a high-AR handbook estimate inflated 15\% so the rate is harder to achieve. Acceptance: $p \ge 35^\circ/\mathrm{s}$ at loiter speed ($\sim 20^\circ$ bank in about a second). A 10\,cm tip strip on this wing makes $\sim 5^\circ/\mathrm{s}$ --- that was the sim.

Weathercock and yaw damping (two NACA~0010 fins, Helmbold $a_v$, $\eta=0.90$, no endplate credit):

\begin{equation}
  C_{n_\beta} = \eta a_v V_V, \qquad
  C_{n_r} = -2\eta a_v \frac{S_V}{S}\left(\frac{\ell_v}{b}\right)^2.
\end{equation}

Floors: $C_{n_\beta}\ge 0.10$, $|C_{n_r}|\ge 0.030$ are \textbf{off} (differential thrust is the yaw effector). Derivatives are still computed. Hinge/side-gap drag of ailerons and elevons is added to the polar.

Differential-thrust yaw (one motor $T_{\max}$, the other idle) must overpower weathercock at $5^\circ$ $\beta$. The \textbf{corrective rate} is the still-air heading rate with loiter-preserving $\Delta T$ (one motor up, the other down, sum held at drag) versus $C_{n_r}$:

\begin{equation}
  r = \frac{N_{\mathrm{DT,loiter}}}{q S b\, |C_{n_r}|\, b/(2V)},
  \qquad
  N_{\mathrm{DT,loiter}} = 2\min(T_{\mathrm{cruise}},\, T_{\max}-T_{\mathrm{cruise}})\, y_{\mathrm{boom}}.
\end{equation}

Acceptance: $r \ge 5^\circ/\mathrm{s}$ (unwind $5^\circ$ in about a second). $C_{n_r}$ for this rate is the \emph{more negative} of handbook vs AeroBuildup. $I_{zz}$ sizes the initial $\dot r$ and the 1-DOF time to yaw $5^\circ$; motor spool-up is not modelled, so those two are optimistic. Max-effort (idle one motor) rate is reported and is not the gate.

\textbf{No dihedral} is modelled. Spiral-mode static stability is not claimed; the autopilot is assumed to hold a slow spiral with the sized ailerons.

\subsection{Washout}
\label{sec:washout}

Geometric washout is tip leading-edge down, starting at a station on the outboard panel. \textbf{Zero washout does not change the lumped polar at all} --- the lifting-line code is not even called. That is deliberate, so the published baseline cannot move when someone toggles a unused twist flag.

When twist is nonzero, a Fourier lifting-line (Prandtl / Anderson, 11 odd modes on the half-span, file \code{solar\_uav/lifting\_line.py}) solves

\begin{equation}
  \Gamma(\theta) = 2 b V \sum_{n=1,3,\ldots} A_n \sin(n\theta),
  \qquad y = (b/2)\cos\theta.
\end{equation}

Section lift $c_\ell = 2\Gamma /(V c)$. Wing $C_L = \pi\,\mathrm{AR}\, A_1$. Trefftz-plane Oswald:

\begin{equation}
  e_\mathrm{LL} = \frac{A_1^2}{\sum n A_n^2}.
\end{equation}

The model does \emph{not} replace handbook $e$ with $e_\mathrm{LL}$ outright (that would let an inviscid method invent a better wing than the calibration). It only reports the \emph{ratio} of twisted to untwisted lifting-line $e$, times the handbook value, still capped at 0.98:

\begin{equation}
  e_\mathrm{eff} = \min\left(0.98,\;
    e_\mathrm{handbook} \frac{e_\mathrm{LL,twisted}}{e_\mathrm{LL,untwisted}}\right).
\end{equation}

Strip profile drag is integrated at the collocation stations; only the \emph{increment} vs.\ the same planform untwisted is added. Stall becomes first-strip $C_{L,\max}$, and cannot exceed the untwisted 3D cap.

\begin{examplebox}
\textbf{Example --- why the search refused washout.}
On $\lambda = 0.4$ (and on the current $\lambda \approx 0.60$) the spanload is already near-elliptical, $e$ is already at the 0.98 cap. Twist cannot raise $e$ further. It \emph{can} unload the tip (good for stall) but the first-strip rule and the profile-drag increment make cruise slightly worse. The current search parked washout at $\approx 0^\circ$. On a \emph{rectangular} wing, washout does raise $e$ ($0.90 \to \sim 0.95$), but flying a rectangle to get that twist benefit also adds tip chord, cells, mass, and drops AR. That package still lost on margin. The optimizer's message: \textbf{taper already bought the induced-drag win; do not pay mass for a second copy of the same win.}
\end{examplebox}

\subsection{Worked drag budget (current night cruise)}
\label{sec:dragbudget}

$m = 8.745\,\mathrm{kg}$, $V = 11.42\,\mathrm{m/s}$ ($1.3 V_s$ binds), $\rho = 1.048$, $q = 68.3\,\mathrm{Pa}$, $S = 1.636\,\mathrm{m^2}$.

\begin{center}
\begin{tabular}{@{}lrrr@{}}
\toprule
 & $C_L$ / $C_D$ & Drag [N] & Share \\
\midrule
Net airplane $C_L$ & 0.768 & & \\
Wing $C_L$ & 0.784 & & \\
H-stab $C_L$ & $-0.109$ & & \\
Wing profile (S4310, $\mathrm{Re}_{\bar{c}}\approx 1.84\times 10^5$) & $C_{D_p}=0.0123$ & 1.38 & 44\% \\
Wing induced ($e=0.98$) & $C_{D_i}=0.0094$ & 1.05 & 33\% \\
H-stab profile & & 0.20 & 6\% \\
H-stab induced ($e_H=0.70$) & & 0.018 & 1\% \\
V-stab profile ($C_L=0$) & & 0.14 & 4\% \\
Pods & & 0.17 & 5\% \\
Booms ($\varnothing 25\,\mathrm{mm}$, $L=1.87\,\mathrm{m}$) & & 0.11 & 4\% \\
Control-surface gaps & & 0.10 & 3\% \\
\midrule
\textbf{Total} & $C_D=0.0283$ on $S$ & \textbf{3.16} & \\
Aero power $DV$ & & \textbf{36.1 W} & \\
$L/D$ & 27.1 & & \\
\bottomrule
\end{tabular}
\end{center}

\begin{intuition}
\textbf{Read this table like a designer, not an aerodynamicist showing off.} About 77\% of cruise drag is the wing. Profile now beats induced (44\% vs.\ 33\%) because the airplane is lighter and is forced to fly $1.3 V_s$ instead of aero min-power. Unconstrained min-power is $\sim$9.2\,m/s and $DV \approx 29\,\mathrm{W}$; the speed floor costs about $7\,\mathrm{W}$ of aero and $\sim$10\,W of bus. The entire empennage plus pods plus booms plus gaps is $\sim$0.74\,N. Polishing boom fairings will not close a 158\,Wh night gap. The remaining polar levers at fixed mass are $C_{L,\max}$ (or relaxing $1.3\to 1.2$) and wing profile $C_D$. Span and $e$ are already maxed.
\end{intuition}

Aero power 36\,W is \emph{not} night bus power. The propeller, motor, ESC, and the 5\,W avionics sit between $DV$ and the battery. That chain currently turns 36\,W of aero into $70.2\,\mathrm{W}$ of propulsion plus $5\,\mathrm{W}$ avionics $= 75.2\,\mathrm{W}$ on the bus. Propulsion, not the polar, is where most of the remaining watts live.

% =====================================================================
\section{Solar array}
% =====================================================================

Files: \code{solar\_uav/environment.py}, \code{solar\_uav/components/solar\_array.py}.

\subsection{Sun}

pvlib Ineichen clear-sky at the site, minute resolution. The array is \textbf{horizontal} (wing top). Angle of incidence equals the solar zenith angle.

Plane-of-array irradiance before cells:

\begin{equation}
  E_\mathrm{POA}
    = \underbrace{E_\mathrm{DNI}\cos\zeta \cdot \mathrm{IAM}(\zeta)}_{\text{beam, with reflection}}
    + \underbrace{0.95\, E_\mathrm{DHI}}_{\text{diffuse IAM \flag{}}}.
\end{equation}

Then encapsulation transmission 0.97 \flag{}:

\begin{equation}
  E_\mathrm{eff} = 0.97\, E_\mathrm{POA}.
\end{equation}

IAM is pvlib's physical air/glass model. A horizontal wing at El Mirage ($34.65^\circ\mathrm{N}$) never sees the sun overhead except near noon in June, and even then $\zeta \ne 0$ most of the day. That cosine is the main reason ``battery night'' is longer than civil night.

\subsection{Cell temperature}

No flight-cooling credit. NOCT-style

\begin{equation}
  T_\mathrm{cell} = T_\mathrm{amb} + k\, E_\mathrm{eff},
\end{equation}

with $k$ calibrated so solstice-noon static $T_\mathrm{cell} = 75^\circ\mathrm{C}$ (user requirement). Ambient is a sinusoid, min at 05:00, max at 15:30, between 24 and $40^\circ\mathrm{C}$.

\subsection{Electrical output}

C60 bin I \flag{}: $P_\mathrm{mp} = 3.40\,\mathrm{W}$ at STC. Temperature coefficient $\gamma = -0.32\%/^\circ\mathrm{C}$. Wiring / mismatch / soiling 0.965 \flag{}. MPPT 0.95.

\begin{equation}
  P_\mathrm{bus}
    = N_\mathrm{cells}\, P_\mathrm{mp}
      \frac{E_\mathrm{eff}}{1000}
      \bigl[1 + \gamma (T_\mathrm{cell}-25)\bigr]
      \times 0.965 \times 0.95.
\end{equation}

\subsection{String voltage and power (GVB-8)}

The GVB-8 input range is $0$--$60\,\mathrm{V}$ and it charges a 25\,V bus from a panel that may sit above or below that bus (buck and boost). The old rule ``string Voc must stay below the depleted 6S bus so the converter can always boost'' is therefore dropped. Remaining datasheet caps, evaluated conservatively:

\begin{equation}
  N_{\max} = \min\left(
    \left\lfloor \frac{50}{V_\mathrm{oc}(10^\circ\mathrm{C})} \right\rfloor,
    \left\lfloor \frac{210\,\mathrm{W}}{P_\mathrm{mp,STC}} \right\rfloor
  \right)
  = \min(70, 61) = 61
\end{equation}

on bin I ($V_\mathrm{oc}(10^\circ\mathrm{C})\approx 0.713\,\mathrm{V}$, $P_\mathrm{mp}=3.40\,\mathrm{W}$). The 210\,W recommended panel power binds first. A bay that wants more than 61 cells still needs a second string (extra MPPT mass) or it is illegal under one-string-per-bay.

\begin{examplebox}
\textbf{Example --- extra cells lost.} A mixed-pack rectangular wing with 92--104 cells and extra strings was tried (``just put more solar on''). AR fell to $\sim$16.7, mass rose $\sim$1.4\,kg, night watts rose, and margin got \emph{worse} (about $-184\,\mathrm{Wh}$ vs.\ $-160\,\mathrm{Wh}$ on the tapered 82-cell wing, at the old 410\,g/m booms). Noon already spills. The night does not care that you had 20 more cells at 13:00. It cares that you are heavier and draggier at 02:00.
\end{examplebox}

% =====================================================================
\section{Battery}
% =====================================================================

File: \code{solar\_uav/components/battery.py}.

Two GOLD V1 packs in parallel: 483\,Wh, 23.68\,Ah, 1.278\,kg, 6\,A charge, 313\,W sustained discharge each. Usable energy at the 20\% floor:

\begin{equation}
  E_\mathrm{usable} = 2 \times 483 \times 0.80 = 773\,\mathrm{Wh}.
\end{equation}

SOC is energy-based. Open-circuit voltage is a generic Si-anode Li-ion curve \flag{}, 3.0--4.2\,V/cell, times 6. Internal resistance $45\,\mathrm{m}\Omega$ per pack \flag{}, paralleled.

Terminal power during discharge: $P = V_\mathrm{oc} I - I^2 R$. Chemistry energy removed is $V_\mathrm{oc} I \Delta t$ (you pay $I^2R$ from the bus but it does not come out of SOC as extra capacity --- it is a conversion loss). Charge is the reverse, capped at 6\,A/pack, with a CV taper as $V_\mathrm{oc}$ approaches 25.2\,V.

The march \emph{allows} SOC to fall through 20\% so we can measure how far a miss is. Closure still requires staying above 20\%.

% =====================================================================
\section{The 24-hour energy march}
% =====================================================================

File: \code{solar\_uav/mission.py}. Default step: 5 minutes.

Night and day bus loads are each a single number: propulsion at that density's min-power speed, plus 5\,W avionics. Then, at every timestep,

\begin{align}
  \text{is\_night} &= (P_\mathrm{solar} < P_\mathrm{night}), \\
  P_\mathrm{load} &= \begin{cases}
      P_\mathrm{night} & \text{if night}, \\
      P_\mathrm{day} & \text{if day},
    \end{cases} \\
  P_\mathrm{net} &= P_\mathrm{solar} - P_\mathrm{load}.
\end{align}

\begin{warningbox}
\textbf{Do not mentally replace $P_\mathrm{net}$ with $-P_\mathrm{night}$ at dusk.} If the array is making 60\,W and the load is 75\,W, the pack only supplies 15\,W. Calling that ``night'' and draining 75\,W is how people convince themselves the physics is worse than it is --- and then over-correct with a third pack. The code already counts the shoulders.
\end{warningbox}

The march starts at the \textbf{last afternoon timestep} where $P_\mathrm{net} > 1\,\mathrm{W}$, with SOC $= 1$ (launch / ground charge), wraps 24 hours, then repeats that wrap \textbf{without resetting the pack}. Day 2 is the scored loop: the night is fully counted, and we test that Tuesday is not poorer than Monday.

\textbf{Battery-true night} is hours with $P_\mathrm{solar} < P_\mathrm{night}$. On 21 June at El Mirage ($34.65^\circ\mathrm{N}$) that is \textbf{14.0 hours} on the current airplane, not the $\sim$9.5 hours of civil night. A horizontal wing at this latitude simply does not make cruise power at low sun.

\begin{examplebox}
\textbf{Example --- why ``75\,W $\times$ 14\,h = 1050\,Wh, we need another pack'' is the wrong arithmetic.}
Usable pack is 773\,Wh. Shoulders (dawn/dusk when the array makes some but not all of cruise) contribute on the order of 100+\,Wh that a naive $P\times t$ ignores. The honest integral is still larger than 773\,Wh --- that is why we miss. On the repeating day the nearest-miss bottoms at $\mathrm{SOC}=0.007$ with a $-28\,\mathrm{Wh}$ cycle. Closing is ``about 11\,W off the night bus'' or ``a bit more pack,'' not ``the polar must be twice as good.''
\end{examplebox}

% =====================================================================
\section{Propulsion}
\label{sec:propulsion}
% =====================================================================

Files: \code{solar\_uav/components/propeller.py}, \code{mejzlik.py}, \code{motor.py}, \code{propulsion.py}.

Two motors, two props, thrust split equally. 6S bus, nominal 22.2\,V, climb uses 25.2\,V.

\subsection{Propeller maps}

APC PER3 files (vortex theory) and Mejzlik 2-blade electric maps (in-house BEM / vortex). Both are \textbf{computational, not measured}. Uncertainty factors, applied in \code{PropulsionSystem} (not inside a \code{nominal=True} table read):

\begin{equation}
  T_\mathrm{used} = 0.92\, T_\mathrm{map}, \qquad
  P_\mathrm{used} = 1.08\, P_\mathrm{map}
  \quad \text{\flag{}}.
\end{equation}

Level flight asks the map for $T_\mathrm{need}/0.92$ so the derated thrust still equals drag.

Nondimensional definitions (McCormick / MIT 16.unified):

\begin{equation}
  J = \frac{V}{n D}, \qquad
  T = C_T(J)\, \rho n^2 D^4, \qquad
  P = C_P(J)\, \rho n^3 D^5, \qquad
  \eta = \frac{J C_T}{C_P}.
\end{equation}

$n$ is rev/s, $D$ is diameter in metres. $C_T$ and $C_P$ come from the published map. Density scaling of a tabulated $T,P$ is $\rho/\rho_\mathrm{ref}$ with $\rho_\mathrm{ref} = 1.225\,\mathrm{kg/m^3}$ for APC.

\textbf{Query rule, in order:}

\begin{enumerate}
  \item If this airspeed exists on an RPM block of the table, interpolate $T(\mathrm{RPM})$ at that speed, density-scale, and pick the RPM that makes the required thrust. \emph{If the slowest tabulated RPM that covers this speed already makes enough thrust, stop. Do not slow down further.}
  \item Otherwise fall back to $C_T(J)$ similarity, but only for $J < J_\mathrm{windmill}$ (the advance ratio where $C_T$ crosses zero). Past windmill the blade is a drag device; there is no cruise solution there.
  \item If table and similarity disagree by more than 15\% (\code{PROP\_SANITY\_REL}), raise a \flag{} on the result. The mission still uses the table value when the table was the source.
\end{enumerate}

\begin{warningbox}
\textbf{The $n^2$-scaling bug, as a worked example.}
At fixed $V$, a naive ``I only need a tiny thrust, scale RPM with $\sqrt{T}$'' walks $J = V/(nD)$ \emph{up}. For the APC $22\times12$E, zero-thrust is near $J \approx 0.67$. Night cruise at 10.7\,m/s wants $n \approx 2070$\,RPM ($J \approx 0.58$) on the table. Scaling down to 1190\,RPM puts $J \approx 1.14$, past windmill. Similarity then says $T=0$. The interpolator had been reporting a few newtons and $\sim$62\,W anyway. That is how a closed design appeared out of nothing. The rule ``never $n^2$-scale RPM down at fixed speed once a covering block exists'' exists so this cannot happen again.
\end{warningbox}

\begin{intuition}
\textbf{Intuition for $J$.} $J$ is ``how much air is rushing at the prop compared to how fast the blades are spinning.'' Small $J$: hovering / climb, blades see mostly rotation, lots of thrust, lots of power. Large $J$: the airplane has run out in front of the blades; they start to windmill. A high-pitch ``cruise prop'' reaches windmill later (larger $J$), which is why we shortlist pitch ratios $0.40$--$0.85$. Even then, a 21$\times$14 at 10.5\,m/s and 1545\,RPM is at $J \approx 0.76$, and Mejzlik similarity says $C_T \approx 0$ while the table still lists $\sim$1.8\,N per blade --- that is why older nearest-misses on MJ-21$\times$14EL were on the optimistic side of the table. The current airplane flies an APC $16\times12$E at 11.42\,m/s and 2365\,RPM; the FLAG there is shaft power, table $28.0\,\mathrm{W}$ vs.\ similarity $22.8\,\mathrm{W}$ (19\%). Night watts use the table. The FLAG is in the CSV for a reason.
\end{intuition}

\subsection{Motor and ESC}

First-order DC motor. Datasheet $K_v$, $R_i$, $I_0$ at 8.4\,V. Torque constant $K_t = 1 / K_{v,\mathrm{rad}}$. Gearbox (if any) ratio $g$, efficiency 0.96 \flag{}. Direct drive pays no gearbox loss.

Given propeller torque $Q_p$ and RPM $n_p$:

\begin{align}
  Q_m &= \frac{Q_p}{g\,\eta_\mathrm{gear}}, \qquad
  n_m = n_p\, g, \\
  I &= \frac{Q_m}{K_t} + I_0, \\
  V &= I R_i + \frac{n_m}{K_v}, \\
  P_\mathrm{bus,1} &= \frac{V I}{\eta_\mathrm{ESC}}.
\end{align}

$I_0$ is still paid when loaded --- it is iron + friction, not ``only at idle.'' Two motors: $P_\mathrm{bus} = 2 P_\mathrm{bus,1}$. A point with $V > 22.2\,\mathrm{V}$ is infeasible at cruise (climb is allowed to 25.2\,V).

$\eta_\mathrm{ESC} = 0.95$ \flag{}. The code does \emph{not} currently inflate that loss when duty is below 50\%, but \code{ESC\_DUTY\_MIN = 0.50} exists as a documented warning. On the current 12L + $16\times12$E at night, $V \approx 6.0\,\mathrm{V}$ at 2365\,RPM, i.e.\ duty $\sim$27\% on a 22.2\,V pack. \textbf{Real ESC efficiency at that duty is worse than 95\%.} Treating 0.95 here is an optimistic FLAG on night bus. A rewind to $K_v \approx 180$--$220$ would put duty at or above 50\%; at fixed $(Q,\mathrm{RPM})$ the 12L rewind model says cruise bus watts are nearly independent of $K_v$, so the catalog kv410 is not a modelled watt win.

\begin{intuition}
\textbf{Intuition for $I = Q/K_t + I_0$.} $Q/K_t$ is the current that actually makes torque. $I_0$ is the current the motor drinks just to spin itself --- hysteresis, windage, bearings. At climb, $Q/K_t$ dwarfs $I_0$ and you barely notice. At night cruise the torque is tiny, so $I_0$ is a large fraction of the bill. That is why a high-$I_0$ motor can look fine on a power-limit datasheet and still lose the night.
\end{intuition}

\subsection{Free-$K_v$ rewind model}

Not a catalog part. Same A40-12L stator, $R_i \propto 1/K_v^2$, $I_0 \propto K_v$. Used to decide what $K_v$ to shop for. At fixed $(Q, n)$, cruise bus power is nearly independent of $K_v$ once you are voltage-feasible --- winding changes trade voltage for current. The 12L wins against the geared 10L because of \textbf{$I_0$ and gearbox loss}, not because 410\,rpm/V is magic.

\subsection{Motors evaluated}
\label{sec:motors}

Catalog in \code{MOTOR\_CATALOG}:

\begin{center}
\begin{tabular}{@{}lrrrrrr@{}}
\toprule
Name & $K_v$ & $R_i$ [$\Omega$] & $I_0$ [A] & $g$ & Mass [kg] & $P_\max$ [W] \\
\midrule
A40-10L V2 kv1100 + 6.7:1 PG & 1100 & 0.019 & 1.70 @ 8.4\,V & 6.7 & 0.315 & 2200 \\
A40-10S V4G kv1600 + 6.7:1 PG & 1600 & 0.012 & 2.75 @ 8.4\,V & 6.7 & 0.247 & 1500 \\
A40-12L V4 kv410 direct & 410 & 0.039 & 1.04 @ 8.4\,V & 1.0 & 0.275 & 1100 \\
\bottomrule
\end{tabular}
\end{center}

Plus the rewind grid $K_v = 180, 200, \ldots, 900$ on the 12L stator (direct drive).

\begin{examplebox}
\textbf{Example --- why 12L beat 10L.}
The 10L is the Hacker ``gliders to 14\,kg, props to 23\,in'' recommendation. It is \emph{not} the search default. At night the prop wants $\sim$1500--2000\,RPM and a few tenths of a newton-metre. After the 6.7:1 gearbox the \emph{motor} is spinning at 10--13\,kRPM and still paying $I_0 = 1.7\,\mathrm{A}$ plus 4\% gearbox. The 12L's $I_0 = 1.04\,\mathrm{A}$ is at the shaft RPM you actually want, with no gearbox. Climb on the 12L + $16\times12$E is still $\sim$15\,m/s. The 10S is worse still ($I_0 = 2.75\,\mathrm{A}$). \textbf{Mindset: size the motor for night $I_0$ and map bite, not for takeoff marketing.}
\end{examplebox}

\subsection{Propellers evaluated}
\label{sec:props}

Shortlist rule (\code{shortlist\_props}):

\begin{itemize}
  \item APC style containing ``E'' (electric), excluding MR, SF, W, N, F2B, 3-blade, 4-blade.
  \item Mejzlik 2-blade electrics (style contains E).
  \item Diameter $\ge 16\,\mathrm{in}$ (no upper cap; climb + cruise decide).
  \item Pitch / diameter $\in [0.40, 0.85]$.
\end{itemize}

That is \textbf{51} maps. Full list in Appendix~\ref{app:props}.

Neighborhood searches used a 7-prop subset that had already survived earlier ranks:

\begin{center}
\texttt{MJ-21x14EL}, \texttt{16x12E}, \texttt{17x12E}, \texttt{18x12E},
\texttt{19x12E}, \texttt{20x13E}, \texttt{21x13E}.
\end{center}

The inner loop currently picks \texttt{16x12E} on the 12L nearest-miss. Larger tabulated diameters cost night watts on-map; similarity-filled points (e.g.\ a $20\times15$E off the table) are excluded. Mejzlik 21-inch fans still appear in the shortlist and in older CSVs, but they are not the current pick.

APC thin-electric mass (when not in a catalog) is the fit $m = 0.263\times 10^{-3}\, D_\mathrm{in}^{1.96}$ \flag{}.

% =====================================================================
\section{Current nearest-miss (does not close)}
% =====================================================================

From \code{outputs/phase4\_candidates.csv} (812 scored, 0 closed), best row of the 17 August 2026 search after independent tails, $0.8\times$ wing areal mass, and 1\,in / $0.174\,\mathrm{kg/m}$ booms. Those numbers are also \code{REF\_*} in \code{config.py} for the visualizer. Washout chose $\approx 0^\circ$.

\begin{center}
\begin{tabular}{@{}ll@{}}
\toprule
Item & Value \\
\midrule
Motor & A40-12L V4 kv410 direct \\
Prop & APC $16\times12$E \\
Wing & $5.907\times 0.314\,\mathrm{m}$, $\lambda=0.598$ from 0.275 of the outboard \\
Area / AR / $e$ & $1.636\,\mathrm{m^2}$, 21.3, 0.98 (cap) \\
H-stab / V-stab arm & $1.278\,\mathrm{m}$ / $1.696\,\mathrm{m}$ (V LE $0.19\,\mathrm{m}$ behind H TE) \\
Boom spacing / elevator & $1.133\,\mathrm{m}$ / 34\% chord \\
$V_H$ actual / $V_V$ & $0.687$ (packing chord floor) / $0.030$ \\
H-stab height / downwash $k$ & $z_H=0$ (wing plane) / $k_\varepsilon=1.21$ (VLM $>$ handbook) \\
Static margin & 43\% MAC \\
Array & 76 cells, strings $26+26+16+8$ (4 MPPTs) \\
Mass & $8.745\,\mathrm{kg}$ (booms $1.868\,\mathrm{m}$, $\varnothing 25.4\,\mathrm{mm}$) \\
Night / day bus & $75.2\,\mathrm{W}$ / $76.5\,\mathrm{W}$ (includes 5\,W avionics) \\
$V_\mathrm{stall}$ / $V_\mathrm{night}$ & $8.78$ / $11.42\,\mathrm{m/s}$ ($1.3 V_s$ binds) \\
Climb & $14.8\,\mathrm{m/s}$ (requirement 1.5) \\
Battery-true night & 14.0\,h \\
$\mathrm{SOC}_\mathrm{min}$ / $\mathrm{SOC}_\mathrm{end}$ & 0.036 / 0.887 \\
Margin & $\mathbf{-158\,\mathrm{Wh}}$ \\
Closed? & No \\
\bottomrule
\end{tabular}
\end{center}

Mass lumps (kg): batteries 2.56, wing 2.25, fixed 1.20, booms 0.65, solar 0.61, motors 0.55, MPPTs 0.43, H-stab 0.22, V-stabs 0.15, props 0.12.

The same search family is lighter than the old 1.5\,in / $0.290\,\mathrm{kg/m}$ $\pi$-tail nearest-miss ($\sim$9.8\,kg, $-112\,\mathrm{Wh}$ at a slower $V_\mathrm{night}$). Independent $\ell_v$, thinner booms, and the $0.8\times$ wing cut mass, but El Mirage density plus the $1.3 V_s$ floor put night bus back at 75\,W and the SOC floor at 0.036. Still about 11\,W of night bus short of the 20\% floor, before you even discount the prop-map and ESC-duty FLAGs.

Prop FLAG on this row: at 2365\,RPM, 11.42\,m/s, table shaft $28.0\,\mathrm{W}$ vs.\ similarity $22.8\,\mathrm{W}$ (19\%). Night watts use the table. ESC duty is $\sim$27\%; the 95\% ESC efficiency is optimistic.

% =====================================================================
\section{Top learnings: design priority and mindset}
% =====================================================================

These are not slogans. They are what the model has already spent compute to tell us.

\subsection{Night is the only constraint that is close}

Day array $\sim$200\,W vs.\ $\sim$75\,W cruise. Climb is an order of magnitude above requirement. MTOW has $\sim$3\,kg of unused budget on the nearest-miss. Span is at the wall. The SOC floor on the repeating day is what fails. \textbf{Every other subsystem is a servant of night bus watts and night duration.}

\subsection{Mass and induced drag beat parasite tricks}

Equation~\eqref{eq:cdi} with $C_L \propto W/S$ means

\begin{equation}
  D_i \propto \frac{W^2}{\rho V^2 b^2 e}.
\end{equation}

Span is maxed. $e$ is capped. At \emph{fixed} mass the remaining polar lever is the $1.3 V_s$ speed floor (true aero min-power is $\sim$9.2\,m/s). If mass is still free, a kilogram of boom is not ``structure we can live with''; it is $C_L$ we fly for 14 hours. Fairings, trip dots, and boom $\varnothing$ are a few percent of drag. Do not spend the team's year there until night bus is honest and the structure is light.

\subsection{The propeller map bite is bigger than the polar}

Aero power is 36\,W. Bus is 75\,W. The missing $\sim$39\,W is prop efficiency at cruise $J$, $I_0$, the 95\% ESC at 27\% duty, and the derate/inflate factors. Chasing 2\% on S4310 $c_d$ saves tenths of a watt of aero. Putting the blade on a tabulated point with real $C_T$, or accepting that a fan is past windmill and picking another, moves tens of watts. The current $16\times12$E is already the best \emph{on-map} fan in the shortlist.

\subsection{Do not invent operating points}

If the map does not list a gentle cruise RPM at that speed, the airplane cannot have that cruise. Similarity past $J_\mathrm{windmill}$ is not a loiter mode. This is the single most expensive lesson in the repo.

\subsection{Taper first, cells second, washout last}

Taper $\lambda\approx 0.60$ from 0.28 of the outboard: fewer tip cells than a rectangle, AR 21.3, $e$ at the cap, Voc-legal strings. Older searches that dropped taper to glue more cells on the outboard made the night worse. Washout on the current wing is $\approx 0^\circ$. \textbf{Do not undo a planform that already matches the ellipse in order to print more silicon that spills at noon.}

\subsection{Motors: night $I_0$, not takeoff watts}

The 10L is the brochure motor. The 12L is the night motor. Climb still clears 1.5\,m/s by a huge margin ($\sim$15\,m/s on the $16\times12$E). Catalog kv410 is 27\% ESC duty; a rewind to $\sim$200\,rpm/V would make the 95\% ESC assumption honest without changing cruise watts in the rewind model. If a future motor has lower $I_0$ at 2000--2400\,RPM on 6S, that is worth more than another 100\,W of burst rating.

\subsection{Closing moves that actually scale}

Roughly 11\,W off night bus, or a third pack (currently forbidden), or array that produces cruise power at lower sun (camber / incidence of the cells, not more noon area). At fixed mass, raising $C_{L,\max}$ (or relaxing $1.3\to 1.2$) is the polar move that actually changes the speed you fly. T-tail downwash credits, $\pi$-tail endplate credits, and flight cooling of the cells are not those moves --- and they are conservative-physics violations if taken as free gains.

\subsection{Mindset}

\begin{itemize}
  \item Prefer an honest fail over an optimistic close.
  \item When two models disagree, take the worse number and write a FLAG, do not average them toward closure.
  \item Unused MTOW is not a license to add mass ``because we can.'' Mass is night watts.
  \item Unused climb is not a license to pick a thirstier motor ``because we have thrust.''
  \item Noon solar that spills is not endurance. Morning solar that covers cruise earlier \emph{is}.
\end{itemize}

% =====================================================================
\section{What this model does not do}
% =====================================================================

New members should not assume the following are in the physics:

\begin{itemize}
  \item 3D CFD, vortex-lattice of the full airplane, or measured glide polars (Phase 6 is the hook for those).
  \item Ground effect, banked turns, gusts, or a control-law simulation.
  \item Propeller--wing interference, swirl recovery, or blade-element theory we wrote ourselves.
  \item Measured ESC efficiency vs.\ duty; measured pack DCIR; measured cell temperature in flight.
  \item Structural sizing (spars are inside the areal density, not a beam model). No aeroelasticity.
  \item Weather other than clear-sky Ineichen. No clouds, no albedo from water, no horizon masking.
  \item Takeoff roll, landing, or a 89-hour trace with degrading packs --- only a two-day march (launch-full, then a repeating 24\,h loop).
  \item Payload, retracts, or a third pack (locked out).
\end{itemize}

Phase 5 (\code{monte\_carlo.py}) samples irradiance, cell temperature, array efficiency, mass growth, drag, prop factors, avionics, and pack energy, and reports $P(\mathrm{closure})$ and a tornado. It does not invent new physics; it shakes the FLAGGED knobs. Phase 6 is bench/flight protocols to replace those knobs with measurements.

% =====================================================================
\section{FLAGGED assumptions (complete working list)}
% =====================================================================

Grep \texttt{FLAGGED} in \code{solar\_uav/config.py} and the component modules. The important ones, with the conservative direction:

\begin{center}
\begin{tabular}{@{}p{0.42\textwidth}p{0.50\textwidth}@{}}
\toprule
Assumption & Conservative direction \\
\midrule
Longitude $-117.606^\circ$ (El Mirage) & $\pm 0.5^\circ$ is $\sim$2 min of solar clock; not a closure driver \\
Field elevation $865\,\mathrm{m}$ + 400\,ft AGL & already thin; sea-level density would be kind \\
Stall margin 1.2 / loiter $1.3 V_s$ and 1.5\,m/s climb & operational, not physics; $1.3 V_s$ binds night watts \\
C60 bin I & worse bins make less power \\
Cell / interconnect mass 6.5 + 1.5\,g & heavier cells hurt \\
Encapsulation 0.97, wiring 0.965, IAM diffuse 0.95 & less array \\
Cold cells $10^\circ\mathrm{C}$ for Voc & 50\,V recommended Voc (not the old 19.2\,V bus cap) \\
GVB-8 50\,V Voc / 210\,W panel & 61 cells/string on bin I; not the old 26-cell bus cap \\
Pack $R_i = 45\,\mathrm{m}\Omega$, generic OCV & more $I^2R$, slightly worse SOC accounting \\
Gearbox 0.96, ESC 0.95, ESC duty 50\% & 0.95 at 27\% duty (kv410 + $16\times12$E) is \emph{optimistic} --- noted \\
Prop $T\times 0.92$, $P\times 1.08$ & unkind to maps; table-vs-similarity FLAG can still be kind \\
Wing areal $0.84\times 0.8$\,kg/m$^2$ wetted, no spar-span scaling & user build number; may still be kind on a 6\,m spar \\
Boom $0.174\,\mathrm{kg/m}$, $\varnothing 25.4\,\mathrm{mm}$ & user build number; parasite uses the OD \\
Pod wetted from CAD, $C_f$ fully turbulent & extra parasite \\
$e_0 = 0.90$ rectangle, cap 0.98 & cap prevents taper from claiming $e=1$ \\
Downwash $2C_L/(\pi\mathrm{AR})$, no T-tail credit; $z_H=0$ & extra tail download; VLM $k=1.21$ is used (worse) \\
$C_{L,\max}$ 0.90 of 2D & higher $V_s$, higher $V_{\min}$ \\
CG at $c/4$, SM target 0.12 / min 0.08 & CG-aft would help trim; we do not take it \\
Elevator $\tau=\sqrt{c_e/c}$ & control check, not polar \\
$V_H=0.50$ (actual 0.69 from packing), $V_V=0.030$, no fin-area floor, $\mathrm{AR}_V=1.5$ & geometry / mass / yaw; no $\pi$-endplate credit \\
$T_\mathrm{amb}$ 24--40\,$^\circ\mathrm{C}$, static 75\,$^\circ\mathrm{C}$ cells & hot, no flight cooling \\
Ineichen $\pm 3\%$ 1-sigma & Phase 5 samples this \\
\bottomrule
\end{tabular}
\end{center}

If you cannot tell which way an effect goes, pick the way that makes night bus higher or SOC worse, and say so in a FLAG. Do not silently undo a conservative factor to help a candidate close.

% =====================================================================
\section{Code map}
% =====================================================================

\begin{center}
\begin{tabular}{@{}ll@{}}
\toprule
File & Role \\
\midrule
\code{solar\_uav/config.py} & locked constants, grids, FLAGGED notes \\
\code{solar\_uav/environment.py} & pvlib sun, IAM, design-day $T$, NOCT cells \\
\code{solar\_uav/asb\_physics.py} & VLM / LL / AeroBuildup / mesh inertia / XFoil envelope \\
\code{solar\_uav/aircraft.py} & geometry (independent $\ell_t$, $\ell_v$), mass, polar, trim, stall, SM, roll/yaw \\
\code{solar\_uav/lifting\_line.py} & Fourier LL, used only if washout $>0$ \\
\code{solar\_uav/mission.py} & 24\,h march, margin, closure \\
\code{solar\_uav/optimize.py} & continuous DE (includes $\ell_v$), legacy grid, inner prop loop \\
\code{solar\_uav/optimize\_kv.py} & free-$K_v$ rewind $\times$ tabulated prop at fixed airframe \\
\code{solar\_uav/cad.py} / \code{cad\_server.py} & OpenSCAD + Three.js viewer on port 8099 \\
\code{solar\_uav/components/airfoils.py} & NeuralFoil polars \\
\code{solar\_uav/components/solar\_array.py} & C60, GVB-8 string cap, bay packing \\
\code{solar\_uav/components/battery.py} & GOLD V1 SOC, 6\,A charge, $I^2R$ \\
\code{solar\_uav/components/propeller.py} & APC maps, similarity, no $n^2$-down \\
\code{solar\_uav/components/mejzlik.py} & Mejzlik maps \\
\code{solar\_uav/components/motor.py} & $K_v, R_i, I_0$, rewind model \\
\code{solar\_uav/components/propulsion.py} & matching, shortlist, climb thrust \\
\code{solar\_uav/monte\_carlo.py} & Phase 5 uncertainty \\
\code{solar\_uav/validation.py} & Phase 6 bench hooks \\
\code{.cursor/rules/conservative-physics.mdc} & the physics rule agents must follow \\
\bottomrule
\end{tabular}
\end{center}

\begin{verbatim}
.venv/bin/python scripts/validate_all.py    # Phases 1-2
.venv/bin/python scripts/eval_stability.py  # aileron / fin / loiter checks
.venv/bin/python scripts/run_asb_audit.py   # AeroSandbox vs handbook envelope
.venv/bin/python scripts/run_phase34.py     # Phases 3-4 + optimizer
.venv/bin/python scripts/run_phase56.py     # Phases 5-6 + CAD
.venv/bin/python scripts/visualize.py       # CAD / HTML viewer (http://127.0.0.1:8099/)
.venv/bin/python -m solar_uav.cad_server    # viewer only, if CAD already exported
\end{verbatim}

Constants that describe the current nearest-miss for the visualizer live at the bottom of \code{config.py} as \code{REF\_*}. Changing those does not re-run the search; it only changes what the CAD and Phase 5 treat as ``the airplane.''

% =====================================================================
\appendix
\section{Full propeller shortlist}
\label{app:props}
% =====================================================================

Electric 2-blade APC + Mejzlik maps that pass diameter $\ge 16\,\mathrm{in}$ and pitch ratio $0.40$--$0.85$ as of this writing ($N=51$).

\begin{center}
\begin{longtable}{@{}llrr@{}}
\toprule
Manufacturer & Name & Diameter [in] & Pitch [in] \\
\midrule
\endfirsthead
\toprule
Manufacturer & Name & Diameter [in] & Pitch [in] \\
\midrule
\endhead
APC & 16x7E(3D) & 16.0 & 7.0 \\
APC & 16x8E & 16.0 & 8.0 \\
APC & 16x10E & 16.0 & 10.0 \\
APC & 16x12E & 16.0 & 12.0 \\
APC & 17x7E & 17.0 & 7.0 \\
APC & 17x8E & 17.0 & 8.0 \\
APC & 17x10E & 17.0 & 10.0 \\
APC & 17x12E & 17.0 & 12.0 \\
APC & 18x8E & 18.0 & 8.0 \\
APC & 18x10E & 18.0 & 10.0 \\
APC & 18x12E & 18.0 & 12.0 \\
APC & 19x8E & 19.0 & 8.0 \\
APC & 19x10E & 19.0 & 10.0 \\
APC & 19x12E & 19.0 & 12.0 \\
APC & 20x8E & 20.0 & 8.0 \\
APC & 20x10E & 20.0 & 10.0 \\
APC & 20x11E & 20.0 & 11.0 \\
APC & 20x13E & 20.0 & 13.0 \\
APC & 20x15E & 20.0 & 15.0 \\
APC & 205x14E & 20.5 & 14.0 \\
APC & 21x13E & 21.0 & 13.0 \\
APC & 22x10E & 22.0 & 10.0 \\
APC & 22x12E & 22.0 & 12.0 \\
APC & 24x12E & 24.0 & 12.0 \\
APC & 25x125E & 25.0 & 12.5 \\
APC & 26x13E & 26.0 & 13.0 \\
APC & 26x15E & 26.0 & 15.0 \\
APC & 27x13E & 27.0 & 13.0 \\
Mejzlik & MJ-18x8E & 18.0 & 8.0 \\
Mejzlik & MJ-18x8EL & 18.0 & 8.0 \\
Mejzlik & MJ-18x10E & 18.0 & 10.0 \\
Mejzlik & MJ-20x8E & 20.0 & 8.0 \\
Mejzlik & MJ-20x8EL & 20.0 & 8.0 \\
Mejzlik & MJ-20x10E & 20.0 & 10.0 \\
Mejzlik & MJ-20x10EL & 20.0 & 10.0 \\
Mejzlik & MJ-20x11E & 20.0 & 11.0 \\
Mejzlik & MJ-20x11EW & 20.0 & 11.0 \\
Mejzlik & MJ-20x11EWL & 20.0 & 11.0 \\
Mejzlik & MJ-20x13E & 20.0 & 13.0 \\
Mejzlik & MJ-20x13EL & 20.0 & 13.0 \\
Mejzlik & MJ-20p5x12EW & 20.5 & 12.0 \\
Mejzlik & MJ-20p5x12ELW & 20.5 & 12.0 \\
Mejzlik & MJ-21x10EL & 21.0 & 10.0 \\
Mejzlik & MJ-21x13E & 21.0 & 13.0 \\
Mejzlik & MJ-21x13EL & 21.0 & 13.0 \\
Mejzlik & MJ-21x13p5EL & 21.0 & 13.5 \\
Mejzlik & MJ-21x14EL & 21.0 & 14.0 \\
Mejzlik & MJ-22x12EW & 22.0 & 12.0 \\
Mejzlik & MJ-24x10EL & 24.0 & 10.0 \\
Mejzlik & MJ-26x15E & 26.0 & 15.0 \\
Mejzlik & MJ-26x15EL & 26.0 & 15.0 \\
\bottomrule
\end{longtable}
\end{center}

\section{C60 bins (datasheet, unlaminated, STC)}

\begin{center}
\begin{tabular}{@{}lrrrrrr@{}}
\toprule
Bin & $P_\mathrm{mp}$ [W] & $V_\mathrm{mp}$ & $I_\mathrm{mp}$ & $V_\mathrm{oc}$ & $I_\mathrm{sc}$ & $\eta$ \\
\midrule
G & 3.34 & 0.574 & 5.83 & 0.682 & 6.24 & 0.218 \\
H & 3.38 & 0.577 & 5.87 & 0.684 & 6.26 & 0.221 \\
I (default) & 3.40 & 0.581 & 5.90 & 0.686 & 6.27 & 0.223 \\
J & 3.42 & 0.582 & 5.93 & 0.687 & 6.28 & 0.225 \\
\bottomrule
\end{tabular}
\end{center}

\section{How to compile this note}

The illustrated Overleaf pack (figures, charts, three-view) is \code{docs/overleaf/}: upload that folder, or the zip next to it, and compile \code{main.tex} with pdfLaTeX twice.

\begin{verbatim}
cd docs/overleaf
pdflatex main.tex
pdflatex main.tex
\end{verbatim}

Regenerate plots with \code{scripts/export\_overleaf\_figures.py}. Numbers are from the live model on 17 August 2026 (\code{reference\_design()} plus \code{outputs/phase4\_candidates.csv}).

\end{document}

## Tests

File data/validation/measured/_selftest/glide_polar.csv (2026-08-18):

v_ms | drag_n
10.452054494002654 | 4.7616791318123965
11.068492883557916 | 4.572052280226309
11.684931273113175 | 4.55663621770329
12.301369662668437 | 4.553603865851577
12.917808052223696 | 4.464724659264093
13.534246441778958 | 4.447874165156038
14.150684831334218 | 4.578800639496692
14.767123220889479 | 4.694749201486622
15.38356161044474 | 4.9211871997001655
16.0 | 4.929293142228811

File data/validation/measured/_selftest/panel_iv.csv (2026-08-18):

g_poa_w_m2 | t_cell_c | p_dc_w
200.0 | 33.0 | 6.9984651962212245
253.33333333333334 | 35.13333333333333 | 8.919259765958033
306.6666666666667 | 37.266666666666666 | 10.706539214818438
360.0 | 39.4 | 12.265340517046685
413.33333333333337 | 41.53333333333333 | 14.011488587176324
466.6666666666667 | 43.66666666666667 | 15.669257736250794
520.0 | 45.8 | 17.524437377381528
573.3333333333334 | 47.93333333333334 | 19.061156563608513
626.6666666666667 | 50.06666666666667 | 20.84694392612317
680.0 | 52.2 | 21.87509098193098
733.3333333333334 | 54.333333333333336 | 24.22876583517393
786.6666666666667 | 56.46666666666667 | 25.372696455411397
840.0 | 58.6 | 27.096280678203957
893.3333333333334 | 60.733333333333334 | 28.36422094770349
946.6666666666667 | 62.86666666666667 | 29.75348511569738
1000.0 | 65.0 | 31.449240975137766

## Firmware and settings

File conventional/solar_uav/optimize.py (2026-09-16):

"""Phase 4 — design-space search.

Aero variables (span, chord, H-stab arm, V-stab arm, boom spacing, taper,
washout, elevator fraction) are continuous. Integer / catalog quantities stay
discrete: cell count (from packing), pack count, motor, ESC. Propellers
are a discrete inner pick (lowest night bus that still climbs).

`search_continuous()` is the production path (differential evolution).
`search()` is the legacy exhaustive grid, kept for neighborhood dumps.
"""

from __future__ import annotations

import os

import numpy as np
import pandas as pd

from . import config, environment
from .aircraft import RHO_DAY, RHO_NIGHT, Design
from .components.propulsion import PropulsionSystem, load_prop, shortlist_props
from .components.motor import drive_for
from .mission import simulate, candidate_score, rank_candidates

# Process-pool state for parallel differential evolution (spawn-safe).
_DE_WORKER: dict = {}


def _init_de_worker(env, motor_key, prop_names, prop_cache, n_packs,
                    one_string_per_bay):
    drive = drive_for(motor_key)
    systems = {n: PropulsionSystem(prop=prop_cache[n], motor=drive)
               for n in prop_names}
    _DE_WORKER.update(
        env=env, motor_key=motor_key, prop_names=list(prop_names),
        prop_cache=prop_cache, drive=drive, systems=systems,
        n_packs=int(n_packs), one_string_per_bay=bool(one_string_per_bay),
    )


def _eval_vector(x):
    """Score one DE vector in a worker. Returns (score, row_or_none)."""
    x = np.asarray(x, dtype=float)
    w = _DE_WORKER
    d = design_from_x(
        x, n_packs=w["n_packs"], motor_name=w["motor_key"],
        one_string_per_bay=w["one_string_per_bay"])
    row = evaluate_design(
        d, w["env"], w["prop_names"], w["prop_cache"], w["drive"], w["systems"])
    if row is None:
        return 1.0e6, None
    return candidate_score(row), row


def _prop_candidates(max_n: int | None = None) -> list[str]:
    """Every shortlisted electric prop. No diameter-cap subsample."""
    idx = shortlist_props()
    if idx.empty:
        raise RuntimeError("No electric APC/Mejzlik props in the catalog window")
    names = idx["name"].tolist()
    if max_n is not None and len(names) > max_n:
        names = names[:max_n]
    return names


def _hard_constraints(d: Design) -> str | None:
    if d.span_m > config.WINGSPAN_MAX_M + 1e-9:
        return "span"
    if d.mass_kg > config.MTOW_MAX_KG:
        return "mass"
    if not d.solar_feasible():
        return "solar_layout"
    if d.stall_speed() * config.STALL_MARGIN_FACTOR > 25.0:
        return "stall"
    if not d.stability_ok():
        return d.stability_fail_reason() or "stability"
    if d.boom_length <= 0.4:
        return "boom"
    if d.vstab_le_x() + 1e-9 < d.hstab_te_x():
        return "vstab_overlap"
    return None


def _best_prop(design: Design, prop_names: list[str],
               cache: dict, motor=None,
               systems: dict | None = None) -> tuple[str, PropulsionSystem, float] | None:
    """Pick the prop with the lowest night bus power that still meets climb.

    Same optimum as testing climb on every fan: rank by cruise power, then
    accept the first that meets the climb rule.
    """
    drive = motor or drive_for(design.motor_name)
    v_night = design.min_power_speed()
    d_night = float(np.asarray(design.drag_n(v_night)).reshape(-1)[0])
    v_day = design.min_power_speed(rho=RHO_DAY)

    ranked: list[tuple[float, str, PropulsionSystem]] = []
    for name in prop_names:
        if systems is not None and name in systems:
            sys = systems[name]
        else:
            sys = PropulsionSystem(prop=cache[name], motor=drive)
        design.prop_diameter_in = sys.prop.diameter_in or 18.0
        design.prop_name = name
        if design.mass_kg > config.MTOW_MAX_KG:
            continue
        fl = sys.level_flight(v_night, d_night, rho=RHO_NIGHT)
        if fl is None:
            continue
        ranked.append((fl["p_bus_w"], name, sys))
    ranked.sort(key=lambda t: t[0])
    for p_bus, name, sys in ranked:
        design.prop_diameter_in = sys.prop.diameter_in or 18.0
        design.prop_name = name
        if design.mass_kg > config.MTOW_MAX_KG:
            continue
        t_max = sys.max_thrust_n(v_day, rho=RHO_DAY)
        roc = design.climb_rate_ideal_ms(v_day, t_max, rho=RHO_DAY)
        if roc >= config.CLIMB_RATE_REQ_MS:
            return name, sys, p_bus
    return None


def _string_options(mixed_strings: bool):
    """Yield (cells_per_string, label) for the outer packing loop."""
    if mixed_strings:
        yield None, "mixed"
        return
    for cps in config.CELLS_PER_STRING_GRID:
        yield int(cps), str(cps)


def _taper_options(pairs=None):
    """Unique (taper_ratio, taper_start_frac) pairs; rectangular once."""
    if pairs is not None:
        for p in pairs:
            yield float(p[0]), float(p[1])
        return
    yield 1.0, 1.0
    for lam in config.TAPER_RATIO_GRID:
        if lam >= 1.0 - 1e-9:
            continue
        for f in config.TAPER_START_FRAC_GRID:
            if f >= 1.0 - 1e-9:
                continue
            yield float(lam), float(f)


def _washout_options(pairs=None):
    """Unique (start_frac, tip_deg). Default is untwisted (legacy searches)."""
    if pairs is None:
        yield 0.0, 0.0
        return
    for p in pairs:
        yield float(p[0]), float(p[1])


def washout_grid() -> list[tuple[float, float]]:
    """Full discrete washout set: zero plus start × tip-angle."""
    out = [(0.0, 0.0)]
    for deg in config.WASHOUT_TIP_DEG_GRID:
        if deg <= 0.05:
            continue
        for f in config.WASHOUT_START_FRAC_GRID:
            out.append((float(f), float(deg)))
    return out


def _boom_options(grid=None):
    vals = config.BOOM_SPACING_GRID_M if grid is None else grid
    for x in vals:
        yield None if float(x) <= 0.0 else float(x)
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

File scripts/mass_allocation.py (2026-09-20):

"""Consistent review hierarchy from the underlying mass model, not CAD lumps."""
import math


def allocation(design, config):
    raw = design.mass_breakdown()
    fixed = dict(config.FIXED_MASSES_KG)
    used_raw, used_fixed = set(), set()

    def node(key, label, mass, children=None, source="", note=""):
        value = float(mass)
        if not math.isfinite(value) or value < 0:
            raise ValueError(f"Invalid mass for {key}: {mass}")
        children = children or []
        if children and not math.isclose(sum(c["mass_kg"] for c in children), value, abs_tol=1e-9):
            raise ValueError(f"Mass allocation does not reconcile: {key}")
        return dict(id=key, label=label, mass_kg=value, children=children, source=source, note=note)

    def modeled(key, label, count=None, item=None, note=""):
        used_raw.add(key)
        mass = raw[key]
        children = []
        if count is not None:
            count = int(count)
            if count < 1:
                raise ValueError(f"Invalid count for {key}")
            children = [node(f"{key}_{i+1}", f"{item} {i+1}", mass/count,
                             source=f"mass_breakdown.{key} / {count}") for i in range(count)]
        return node(key, label, mass, children, f"mass_breakdown.{key}", note)

    def fixed_items(keys):
        rows = []
        for key, label in keys:
            if key in fixed:
                used_fixed.add(key)
                rows.append(node(key, label, fixed[key], source=f"FIXED_MASSES_KG.{key}"))
        return rows

    def group(key, label, children, note, quantity=1, open_items=()):
        result = node(key, label, sum(c["mass_kg"] for c in children), children, note=note)
        result.update(quantity=int(quantity), per_item_kg=result['mass_kg']/quantity,
                      open_items=list(open_items))
        return result

    conventional = config.N_MOTORS == 1
    n_h = int(getattr(config, 'N_HSTABS', 1))
    n_v = int(getattr(config, 'N_VSTABS', 1 if conventional else 2))
    n_booms = int(getattr(config, 'N_BOOMS', 1 if conventional else 2))
    n_fuselages = int(getattr(config, 'N_FUSELAGES', 1 if conventional else 2))
    # Reporting allocation of an existing lump budget, not new hardware sizing.
    servo_counts = {'wing': 2, 'hstab': 1 if conventional else 2, 'vstab': 1 if conventional else 0}
    servo_count = sum(servo_counts.values())
    servo_total = float(fixed.get('servos', 0.))
    if 'servos' in fixed:
        used_fixed.add('servos')

    def servos(assembly, label):
        count = servo_counts[assembly]
        note = (f'Provisional allocation: {count} of {servo_count} assumed equal-mass actuators. '
                'Shares the existing total servo budget; not a selected servo specification.'
                if count else 'No rudder servo in the current differential-thrust configuration.')
        return node(assembly+'_servos', label, servo_total*count/servo_count,
                    source=f'FIXED_MASSES_KG.servos * {count}/{servo_count}', note=note)

    cell_counts = {'wing': 0, 'hstab': 0}
    for cell in design.cell_placements():
        assembly = 'wing' if cell.bay.startswith('wing_') else 'hstab' if cell.bay.startswith('hstab') else None
        if assembly is None:
            raise ValueError(f'Unassigned solar installation: {cell.bay}')
        cell_counts[assembly] += 1
    if sum(cell_counts.values()) != design.n_cells:
        raise ValueError('Solar placement count differs from model cell count')
    cell_mass = config.CELL_MASS_KG + config.CELL_INTERCONNECT_MASS_KG
    if not math.isclose(design.n_cells*cell_mass, raw['solar_cells'], abs_tol=1e-9):
        raise ValueError('Solar constituent masses do not reconcile')
    used_raw.add('solar_cells')

    def solar(assembly):
        count = cell_counts[assembly]
        if not count:
            return []
        return [node(assembly+'_solar', 'Installed solar array', count*cell_mass, [
            node(assembly+'_cell_material', f'Solar cells ({count})', count*config.CELL_MASS_KG,
                 source=f'{count} installed cells * CELL_MASS_KG'),
            node(assembly+'_cell_interconnects', 'Cell interconnects', count*config.CELL_INTERCONNECT_MASS_KG,
                 source=f'{count} installed cells * CELL_INTERCONNECT_MASS_KG'),
        ], source='Cell placements by mounting surface',
           note='Installed cells and interconnects; encapsulation remains in the structure estimate.')]
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

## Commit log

2026-08-18 Initial commit of the solar UAV design toolchain.
    Physics model, optimizer, CAD viewer, Overleaf guide, and search outputs for the twin-boom El Mirage airplane.
    [ag35.csv, aircraft.scad, aircraft.stl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]
2026-08-18 Allow a 3-pack DE search, show night drag on the CAD viewer, and keep the conventional-layout fork.
    DE now runs once per pack count (cap 3). The viewer reports the night drag budget for the nearest-miss airplane.
    [aircraft.scad, aircraft.stl, aircraft_structure.stl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]
2026-08-19 Ship the closed 6 m REF airplane and rebuild AircraftView around it.
    Give a teammate the 102-cell / 3-pack reference, the Mojave-style viewer (3D, mass, power, planform), and the matching CAD and search outputs.
    [aircraft.scad, aircraft.stl, aircraft_structure.stl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]
2026-08-27 Show the aircraft origin and XYZ axes in Aircraft View.
    RGB arrows sit at wing LE (x=0), so the published viewer matches the CAD frame without relying on Three.js Y-up.
2026-09-01 Fold solar into wing/H-stab mass and add constituent dropdowns.
    Aircraft View now shows surface totals with expandable parts, including the fixed-mass list, so the published stack matches how the airframe is built.
2026-09-04 Score split and conventional on the π-tail mission and GVB-8 MPPT, and publish a three-layout AircraftView.
    Aligns energy scoring (two-day march, no 98% refill) and buck/boost string limits, reruns those searches, and deploys the compare viewer to GitHub Pages.
    [aircraft.scad, aircraft.step, aircraft.stl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]
2026-09-10 Publish the 6S 36 Ah pack study in AircraftView with layout and battery sliders.
    [aircraft.step, conventional_phase4.csv, pi_tail_phase4.csv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]
2026-09-16 Publish engineering AircraftView with mass breakdown and eight-case study
    [conventional__6s_36ah.csv, conventional__gold_v1.csv, conventional_rectangular__6s_36ah.csv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]
2026-09-20 Publish five GOLD configurations with assembly mass allocations
2026-09-29 Publish overview battery capacity and solar counts with 88-cell revision
    [conventional_rectangular__gold_v1.csv]
2026-10-15 Report required climb thrust in aircraft overview and energy view
